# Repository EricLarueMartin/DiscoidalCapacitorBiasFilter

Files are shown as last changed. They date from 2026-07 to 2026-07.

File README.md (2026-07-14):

# Discoidal Capacitor Bias Filter

This repository contains the design, simulation, prototyping, and presentation tools for a high-voltage, low-current detector bias filter built from a discoidal capacitor stack. The project is named for the geometry being analyzed; a later implementation is expected to serve SHV connector inputs, but connector packaging is outside the present analysis. The project was developed around an AI-managed Raspberry Pi: the AI works from your computer, connects to the Pi over SSH, installs the solver stack, hosts the web interface, and tests the deployment.

## What You Need

The recommended setup is:

- A Raspberry Pi 5 with 4 GB RAM is the recommended target. The measured default FEniCSx solves also fit comfortably on a 2 GB Pi when the backend runs its normal single worker. A Pi 4 with 2 GB or more should be usable, but finite-element solves will be slower. An 8 GB model is useful for unusually fine meshes or additional development services, but is not required for the present application.
- A 64 GB high-endurance microSD card. A 32 GB card is a practical minimum.
- The correct Raspberry Pi power supply.
- Ethernet or Wi-Fi access to the same network as your computer, with Internet access during installation.
- A Windows, macOS, or Linux computer from which an AI coding agent can edit this repository and connect to the Pi by SSH.
- A microSD card reader for installing Raspberry Pi OS.

A monitor and keyboard for the Pi are optional. Raspberry Pi Imager can preconfigure the network and SSH, and Raspberry Pi Connect is a useful fallback during initial setup.

If you already have a suitable Pi running on your network, use it; the agent runbook begins by discovering what is already complete and skips unnecessary setup.

### Measured Memory Use

Resource monitoring around the actual FEniCSx subprocesses was added before setting the hardware recommendation. With the default two-pair geometry and default meshes on a Raspberry Pi 5, the electric-field solve peaked at 156.5 MiB of solver-process RSS and the thermal-stress solve peaked at 251.8 MiB. Peak total system memory in use was approximately 655 MiB and 771 MiB respectively, and neither solve used swap.

These measurements support 2 GB as a practical minimum and 4 GB as the recommended capacity for ordinary development. They are not hard upper bounds: the FEniCSx direct linear solver can grow substantially faster than the mesh dimensions, so aggressive mesh refinement, larger full-stack models, parallel solves, or unrelated services may need more RAM. The backend intentionally runs one FEA worker at a time. Each solve records its geometry, reduction strategy, peak process memory, lowest available system memory, and swap use in the ignored runtime log `simulations/axisymmetric/logs/fea-resource-usage.jsonl` so this guidance can be updated as larger cases are exercised.

Setting up a Pi is worthwhile beyond this one project. Once provisioned, it becomes a reusable development and test environment for other web services, simulations, instruments, and automation projects. It can communicate over Wi-Fi, run without a monitor or keyboard, and be placed wherever it is convenient for the work at hand while your AI agent continues to control it remotely over SSH.

The recommended trust model is to treat the Pi as an AI development appliance rather than a durable server. Give the dedicated AI account full administrative control, including `NOPASSWD` sudo, so the agent can install packages, change services, reboot, and repair the environment without repeatedly stopping for authorization. Keep source and important results in Git or another external location. If the agent damages the operating system beyond convenient repair, reimaging the microSD card provides a clean recovery path.

This model assumes a dedicated, expendable development Pi with no irreplaceable local data. Do not apply blanket AI access to a shared, production, or security-sensitive server.

## Start With An AI

You are probably reading this README on the project's GitHub page, where GitHub displays it below the repository file list. You do not need to follow a long list of shell commands here. Choose one of the guides below; it will show you how to use the **Code** menu on this page to put the repository on your computer, open it with the AI, and ask the AI to walk you through the setup at whatever level of detail you need.

- [Codex desktop app](docs/getting-started/chatgpt-codex-app.md) - the workflow used to develop this project.
- [Visual Studio Code with the Codex extension](docs/getting-started/vscode-codex.md) - for working beside the files in an editor.
- [Codex command line](docs/getting-started/codex-cli.md) - for a terminal-first OpenAI workflow.
- [Claude Code](docs/getting-started/claude-code.md) - for a terminal-first Anthropic workflow.
- [Another local coding agent](docs/getting-started/other-agent.md) - requirements and a provider-neutral starting prompt.

The agent-facing Raspberry Pi runbook is [deploy/pi/agent-setup.md](deploy/pi/agent-setup.md). Humans can read it, but it is written for an agent that can inspect the local machine, generate an SSH key, substitute the real public key into commands, connect to the Pi, install packages, and verify the result. You should never have to replace `PASTE_PUBLIC_KEY_HERE` or similar placeholder text yourself.

## Optional Local-Computer Setup

If you only want to run this web service, a Raspberry Pi is not required. The browser interface and the project's own Python HTTP backend can run directly on your local computer. No separate web framework is required.

Local hosting is a supported option, but it is not the environment in which the project was developed. The complete FEniCSx path is most straightforward on Raspberry Pi OS or another Debian-based Linux system; on Windows, an agent may recommend WSL 2 for the solver backend.

Tell your chosen agent that you want a local-only installation and have it adapt [deploy/pi/package-requirements.md](deploy/pi/package-requirements.md) to your operating system. It should explain which features it verified and which remain Pi-specific.

## Concept

The filter is based on a cylindrical, discoidal capacitor stack:

- Alternating high-voltage center plates and grounded annular plates.
- A central resistive core in the 100 Mohm to low Gohm range.
- Dielectric between overlapping HV and ground plate regions to provide useful capacitance.
- Lower-permittivity dielectric near the resistive core and outer fringe regions to reduce parasitic capacitance where appropriate.
- Flat ceramic washer slabs in the axial gaps between plate faces, with epoxy fill in rounded-edge pockets and other non-washer voids.
- Separate outer ground rings that can couple to a surrounding tube, allowing adjustment of ground separation between input and output.
- Prototype I/O based on screw terminals, with later revisions expected to directly support SHV bulkhead connectors.

## Repository Map

- `docs/getting-started/` - short human guides for opening the project with an AI agent.
- `deploy/pi/` - agent-facing Raspberry Pi installation and hosting runbooks.
- `docs/knowledge/` - curated design knowledge, requirements, assumptions, and decisions.
- `docs/chats/raw/` - raw AI collaboration transcripts and exported chats.
- `docs/chats/markdown/` - cleaned summaries derived from raw chats.
- `hardware/` - geometry, materials, connector, and prototype design notes.
- `simulations/` - simulation plans, parameter definitions, and solver work.
- `presentations/web/` - the interactive web designer and presentation.
- `software/` - calculation, geometry, solver, and backend code.

## Current Tooling

The repository includes an axisymmetric geometry and electrostatic model:

```powershell
python software/bias_filter/axisymmetric_model.py export
python software/bias_filter/axisymmetric_model.py solve
python software/bias_filter/axisymmetric_model.py cad
```

The browser page at `presentations/web/index.html` mirrors the same first-order r-z model for interactive design changes and peak-field screening. CAD and mesh exports are generated under `hardware/geometry/generated/`.

The JavaScript and Python finite-difference solvers are structured-grid screening tools. The optional FEniCSx/DOLFINx backend uses a conforming Gmsh r-z dielectric domain and reports field and capacitance checks, including an adjacent-bias parasitic-capacitance estimate from a separate three-bias-plate solve. Peak-field results still require mesh-convergence work before they should be treated as validated breakdown limits.

The backend also provides RC-ladder and SPICE-style response calculations using `ngspice` when available, with an internal modified-nodal fallback.

## AI Collaboration

Agents should read the root `AGENT.md`, the nearest directory-specific `AGENT.md`, and [deploy/pi/agent-setup.md](deploy/pi/agent-setup.md) before installing or deploying the project. Hostnames, IP addresses, passwords, private keys, and current deployment paths belong in ignored local files, never in committed documentation.

The current cross-computer continuation note is
[docs/chats/markdown/2026-07-13-current-handoff.md](docs/chats/markdown/2026-07-13-current-handoff.md).

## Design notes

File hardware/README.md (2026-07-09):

# Hardware

Hardware notes are split into:

- `geometry/` - Plate, tube, core, and dielectric geometry.
- `materials/` - Ferrite, dielectrics, metals, resistors, and connector materials.
- `prototypes/` - Build plans and test notes for prototype revisions.
- `degas-controller/` - Vacuum/pressure cycling controller for epoxy void reduction.

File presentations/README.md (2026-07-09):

# Presentations

This section hosts web-based presentations and design views that can be viewed in a browser, version-controlled, and eventually published with GitHub Pages or another static site host.

Start with `web/index.html`. The first screen is an interactive geometry and electric-field design view, with slide material available as a tab.

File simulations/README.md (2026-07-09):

# Simulations

The first simulations should be electrostatic and axisymmetric.

Primary questions:

- What peak electric fields appear at rounded plate edges?
- How sensitive are fields to edge radius and plate gap?
- How much capacitance is produced per discoidal gap?
- How should dielectric boundaries be placed near the end of plate overlap?
- What changes when the outer ground tube is present?

## Current Script Path

The first repository-native model is `software/bias_filter/axisymmetric_model.py`.

It can export geometry and run a compact r-z finite-difference electrostatic solve:

```powershell
python software/bias_filter/axisymmetric_model.py export
python software/bias_filter/axisymmetric_model.py solve
python software/bias_filter/axisymmetric_model.py cad
```

Generated summaries and SVGs are written to `simulations/axisymmetric/outputs/`.
CAD and mesh exports are written to `hardware/geometry/generated/`.

This model treats the central ferrite/resistive core as a conductive HV body for electrostatic field screening. The free dielectric from the core surface to the ground-plate inner radius is epoxy/fill. Washer material is present only as flat annular slabs in the axial gaps between adjacent plate faces. Rounded-edge pockets, tube-side fill, and other non-washer voids are epoxy. Flow holes in the HV plates are omitted from the axisymmetric model and should be checked later with a local 3D study if their dimensions approach high-field regions.

The peak-field search is a global scan over all dielectric grid nodes after solving the potential, not a single-start local optimizer. To reduce the chance that a narrow peak is missed before adaptive refinement, the grid is seeded in three deterministic ways before the probe solve: rounded conductor-edge neighborhoods, dielectric-side points radially away from the HV outer and ground inner plate edges, and washer-region points centered between adjacent plate faces. The later high-field adaptive pass then adds extra coordinates around all dielectric nodes above the configured field threshold.

The current peak is a screening metric. The UI reports `Supported Emax`, based on a same-material local neighborhood, and keeps the raw point maximum as a diagnostic. It includes a near-conductor sliver guard to avoid obvious nonconformal-grid spikes, but mesh sweeps still show that the maximum near rounded conductors can move between edge features. Treat supported and raw peaks as warning indicators and use them for relative comparisons only.

The default washer-overlap field remains the first sanity check for every solver path: with 6 kV across 1 mm, samples away from edges should be about 6.0 kV/mm. This check is now documented because it caught an early FEniCSx boundary-tagging failure. After the 2026-06-25 tolerance fix, both FD and deployed FEniCSx return about 6000 V/mm in the default flat washer gaps.

Field-map colors in the web app use one absolute `V/mm` scale. Dielectric breakdown values may appear as reference ticks and margin readouts, but they should not normalize individual pixels when the colorbar is labeled in kV/mm.

## RF Model Roadmap

The current frequency-response plot is a lumped RC ladder with a parasitic capacitance branch. It is useful for intuition and parameter sweeps, but it is not a field-based RF calculation.

The next field-based comparison should probably be a frequency-domain quasi-static admittance solve before a full-wave model. That solve would use the same axisymmetric geometry and complex material coefficient:

```text
div((sigma + j omega epsilon) grad(V)) = 0
```

This captures dielectric permittivity, dielectric loss if added, finite conductor conductivity, and frequency-dependent current paths while staying close to the existing electrostatic formulation. The web parameters now include plate and tube material names, conductivity `sigma`, relative permeability `mu_r`, and a comparison frequency; defaults use copper for both plates and tube.

A full-wave RF model is a separate tier. FEniCSx-style FEM can represent Maxwell problems with suitable vector/edge elements, but a useful implementation also needs port definitions, radiation or absorbing boundaries/PML where appropriate, conductor loss treatment, and validation against the simpler admittance and lumped RC models. For this filter size and the likely noise frequencies of interest, use the quasi-static admittance backend as the first repository-native RF target.

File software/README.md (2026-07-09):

# Software

This directory is reserved for future project software, including:

- Geometry parameter tools.
- Capacitance and resistance calculators.
- Simulation pre/post-processing.
- Presentation generation tools.
- Data analysis from prototype measurements.

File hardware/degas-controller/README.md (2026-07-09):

# Degas Controller

Subproject for controlling the vacuum/pressure cycling used to reduce voids during epoxy potting.

## Prototype Function

- Control two valves through relays:
  - vacuum valve: opens the chamber to a vacuum pump.
  - pressure valve: opens the chamber to a pressure source, initially vent or nitrogen.
- Read chamber pressure from a pressure gauge or pressure transducer.
- Cycle between low-pressure and high-pressure dwell bands before heat cure.

## User Controls

- Low-pressure target.
- High-pressure target.
- Hysteresis band around each target for valve open/close control.
- Dwell time at each pressure band.
- Number of vacuum/pressure cycles.

## Notes

Pressure curing inside an oven could be useful later, but it is intentionally outside the first prototype scope. The first controller should focus on repeatable degas cycling at room temperature with clear valve-state logging and conservative pressure-vessel safety margins.

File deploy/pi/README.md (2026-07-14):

# Raspberry Pi Web Host

This directory contains reusable Raspberry Pi hosting support for the Discoidal Capacitor Bias Filter web app and solver backend. Keep site-specific hostnames, IP addresses, local checkout paths, passwords, and private keys in ignored local notes such as `.secrets/current-deployment.md`.

The recommended deployment is a dedicated AI development Pi with blanket passwordless sudo for the `agent` account. The agent may administer the machine as needed, while Git or other off-device storage holds the durable copy of the work. Reimage the microSD card if experimentation leaves the OS in an inconvenient state. Use narrower privileges when adapting these files to a shared or production host.

The root README sends humans to a short guide for their chosen coding agent. That agent should then follow [agent-setup.md](agent-setup.md) from the user's current starting point, including OS guidance and creation of dedicated SSH access. Package details are split into [package-requirements.md](package-requirements.md).

## Layout

The agent setup guide uses these variables:

- `PROJECT_DIR` - repository checkout or synced working tree on the Pi.
- `STATIC_ROOT` - web server document root on the Pi.
- `APP_PATH` - URL path for the app, usually `/discoidal-capacitor-bias-filter/`.
- `STATIC_DIR` - static files for the app, usually `STATIC_ROOT` plus `APP_PATH`.
- `SERVICE_NAME` - systemd service name.

The included service file contains placeholders. The setup agent must render it with the user's chosen `AGENT_USER`, `PROJECT_DIR`, and `STATIC_ROOT` before installing it.

## Service

`agent-sites.service` runs the repository's dependency-free Python field backend on port 80 as the agent user. It serves the landing page, the Discoidal Capacitor Bias Filter web app, and `/api/field-solve` job endpoints. The service uses `AmbientCapabilities=CAP_NET_BIND_SERVICE` so it can bind port 80 without running as root.

The backend accepts `--solver fd`, `--solver auto`, and `--solver fenicsx`. The Pi package stack for FEniCSx/DOLFINx/Gmsh is installed and the conforming worker is implemented. The service is still intentionally started with requested/effective default solver `fd` so normal page loads use the faster screening path; use the web dropdown's `FEniCSx required` option when deliberately running the conforming FEA worker.

The systemd unit sets `MemorySwapMax=0`. The backend and all FEniCSx subprocesses therefore stay in the same no-swap cgroup, avoiding solver-driven swap writes on SD-card deployments. If a solve exhausts available RAM, it should fail rather than spill into swap; keep the worker count at one and reduce mesh density for oversized jobs.

## Reporting Access

After setup, the agent must report the actual hostname or IP address it verified, using clickable links for the app and backend health endpoint. Do not commit those current-access details to this repository.

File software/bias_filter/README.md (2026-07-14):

# Bias Filter Tools

`axisymmetric_model.py` provides a lightweight parameterized model for early design iteration.

Examples:

```powershell
python software/bias_filter/axisymmetric_model.py export
python software/bias_filter/axisymmetric_model.py solve
python software/bias_filter/axisymmetric_model.py cad
```

The solver is a first-order finite-difference electrostatic model in an r-z cross-section. It is intended for trend finding, geometry review, and peak-field screening before higher-fidelity validation.

CAD exports are written to `hardware/geometry/generated/` as OpenSCAD, OBJ/MTL, and STL files. The CAD/mesh profiles use the same parameter interpretation as the axisymmetric solver.

## Pi Field Backend

`field_backend.py` stages the HTTP backend that the web designer already tries before falling back to browser JavaScript. It uses only Python's standard library so it can run on a Raspberry Pi without installing a web framework:

```powershell
python software/bias_filter/field_backend.py --host 0.0.0.0 --port 8765
```

Open `http://<pi-hostname-or-ip>:8765/` from the browser. The server exposes:

- `POST /api/field-solve`: accepts `{ "client_id": "...", "solver": "fd|auto|fenicsx", "parameters": { ... } }` and returns a queued `job_id`.
- `GET /api/field-solve/{job_id}`: returns queued, running, failed, or complete job state.
- `POST /api/geometry`: accepts `{ "parameters": { ... } }` and returns the sanitized solver-side r-z component profiles without running a field solve.
- `POST /api/spice-ladder`: accepts `{ "parameters": { ... } }` and returns a SPICE-style small-signal AC ladder sweep, generated netlist text, and summaries for the RC ladder plus coax transmission-line load.
- `POST /api/thermal-solve`: runs the axisymmetric linear-thermoelastic FEniCSx solid model synchronously and returns epoxy tensile-stress percentiles, the raw corner peak, mesh statistics, and model assumptions.
- `GET /api/health`: lightweight server status.

Jobs are independent and write under `simulations/axisymmetric/jobs/{job_id}/`, avoiding shared `latest-*` output files for browser requests. The default worker uses the repository finite-difference axisymmetric solver; explicit FEniCSx jobs run in a subprocess so Gmsh and PETSc are isolated from the web worker thread.

Every electric-field or thermal FEniCSx subprocess is sampled from Linux `/proc` at 0.1 s intervals. The solve tabs show peak solver-process RSS, peak system memory use, lowest available system memory, and maximum system swap use. The backend appends the complete sanitized inputs, solve status, mesh summary, full-stack/mirror/repeating-cell choices, process-tree RSS and swap, and system-memory extrema to `simulations/axisymmetric/logs/fea-resource-usage.jsonl`. This runtime log is intentionally ignored by Git; retain or analyze it on each Pi when developing hardware recommendations.

The first monitored default solves on a Raspberry Pi 5 used 156.5 MiB peak process RSS for the electric FEA and 251.8 MiB for the thermal FEA. Corresponding peak total system use was approximately 655 MiB and 771 MiB, with no swap use. The project therefore recommends 4 GB RAM for comfortable development and treats 2 GB as the practical minimum for the present single-worker service. Fine meshes and larger direct solves can require substantially more memory; continue using the accumulated runtime log rather than treating these first measurements as fixed upper bounds.

The backend has a staged solver selector:

```powershell
python software/bias_filter/field_backend.py --solver fd
python software/bias_filter/field_backend.py --solver auto
python software/bias_filter/field_backend.py --solver fenicsx
```

`fd` is the nonuniform finite-difference screening solver. `auto` may select FEniCSx when the optional package stack is installed and the solver reports ready. `fenicsx` deliberately requires that optional path and fails loudly when it is not ready.

The field backend is still electrostatic. Plate and tube conductivity/permeability parameters are passed through job inputs and summaries so a later frequency-domain admittance or RF backend can consume the same design payload, but the present `fd` solver treats conductors as equipotential boundaries.

The `/api/spice-ladder` endpoint is separate from the electrostatic field solve. On the deployed Pi it uses `ngspice` batch AC analysis when available, with an internal Python modified-nodal AC solve as a fallback for development machines without ngspice. The returned netlist uses ordinary SPICE concepts (`R`, `C`, and a lossless transmission-line `T` element), so the simulation can be inspected or rerun directly in ngspice.

The `/api/thermal-solve` endpoint is also separate from the electrostatic field solve. It meshes the full bonded copper/alumina/epoxy/core r-z solid and uses exact cylindrical and center-plane symmetry. The closed-form differential-contraction estimate remains in the web app as an independent baseline. The FEA assumes perfect bonds, traction-free exposed surfaces, linear elasticity, and a 70 C stress-free reference; it does not model cure shrinkage, relaxation, voids, or debonding.

The backend SPICE sweep and matching web attenuation plots are fixed at 1 Hz to 100 MHz. This makes the low-frequency rolloff around power-line noise easier to read while avoiding excessive very-slow-drift plot space, and 100 MHz is a practical upper view limit for the current detector readout context because the DAQ sample rate is only about 200 MS/s.

The web Designer exposes the same distinction as a dropdown: `Backend adaptive FD` means Python-backed finite difference, not FEniCSx. `FEniCSx required` is the explicit conforming FEA path.

The current `fd` worker solves the cylindrical axisymmetric r-z equation with radial face weighting, not the rectangular-coordinate Laplacian. It is still a nonconformal structured-grid solver. The point maximum near rounded conductor boundaries is labeled as a screening value because it remains mesh-sensitive; the overlap fields away from edges should be checked against `V / gap` and are the better regression sanity check until conforming FEA is available.

Both the FD and FEniCSx workers report a neighborhood-supported peak field plus the raw point maximum. Use the supported value for interactive screening and the raw point as a mesh-artifact diagnostic.

The current FEniCSx worker builds a conforming Gmsh/OpenCASCADE r-z dielectric domain with conductor regions removed as holes, solves the cylindrical weak form in DOLFINx, and samples `|grad(V)|` back onto the browser grid for comparison. It reports total two-terminal capacitance from the axisymmetric dielectric energy integral, `C = 2U/V^2`, and a quasi-static shunt admittance sweep using `Y(f) = Iload/Vbias + j 2 pi f C`. The load-current slider defaults to 1 nA.

The FEniCSx worker also reports an adjacent-bias `Cpar` estimate from a separate local three-bias-plate model. Three energy solves drive the middle plate, both neighbors, and all bias plates respectively; polarization then cancels ground-capacitance terms algebraically. This is an energy-based design sanity check, not yet a full capacitance-matrix charge extraction.

For MELF 0204/0207 presets, the Cpar solves include the inter-plate core as dielectric with an effective permittivity `eps_eff = eps_substrate / (1 - film_fill_factor)`. The default 0207 values are `eps_substrate = 9.8` and `film_fill_factor = 0.50`. In the capacitance-only geometry, each bias plate extends across the core cross-section as a stage-node electrode, but the core between plates remains dielectric. Adjacent-stage mutual capacitance uses three energy solves (middle only, neighbors only, and all bias plates) so polarization cancels capacitance to ground without assuming equal edge and middle ground capacitances. This remains an initial FEA backend, not yet a production acceptance calculation, because the peak-field convergence loop, mesh-refinement records, capacitance-matrix charge extraction, and lossy complex-permittivity FEM admittance solve still need to be added.

The analytic core-plus-epoxy Cpar estimate is intentionally a parallel-plate upper-level sanity check. It does not model field intercepted by the intervening ground-plate inner edge. When the ground-hole radius is comparable to or smaller than the adjacent-bias separation, FEA can therefore report materially less epoxy-mediated adjacent-stage coupling even after the core dielectric treatment is correct.

The Pi solver includes a repeatable Type 61 limiting-geometry comparison. It expands the core-ground radial gap while preserving radial plate overlap and reports FEA/analytic Cpar; that ratio should approach unity as the hole radius becomes large compared with stage spacing:

```bash
python3 software/bias_filter/fenicsx_solver.py --validate-cpar-gap-sweep
```

FEniCSx conductor boundary tagging uses a small geometric tolerance. This is required because Gmsh/DOLFINx boundary coordinates can land infinitesimally outside ideal plate intervals; exact classification previously missed one side of some conductor faces and produced washer-gap fields far below `V / gap`.

The field material model is z-dependent. Flat washer material exists only in the axial gaps between adjacent plate faces and between the explicit washer ID/OD. The defaults tie washer ID to ground plate ID and washer OD to HV plate OD; smaller custom washers leave the newly exposed radial pockets as epoxy.

Keep the flat-gap sanity check in any solver review: for default 6 kV bias and 1 mm washer thickness, samples in the radial and axial middle of each washer overlap should be about 6000 V/mm. The deployed Pi FEniCSx API passed this check on 2026-06-25.

Check optional FEniCSx dependency readiness with:

```powershell
python software/bias_filter/fenicsx_solver.py --json
```

Run backend tests with:

```powershell
python -m unittest software.bias_filter.test_field_backend
```

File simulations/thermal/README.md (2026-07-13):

# Thermal mismatch screen

`software/bias_filter/thermal_stress.py` evaluates the default cured copper,
alumina, and MG Chemicals 9510 assembly with a closed-form restrained-epoxy
model. Run it with:

```powershell
python software/bias_filter/thermal_stress.py
```

The checked-in result is `outputs/default-thermal-stress.json`. It preserves
the source material properties, assumed epoxy modulus range, equations,
geometry dimensions, a room-temperature evaluation point, failure-onset
sensitivity limits, and interim transport guidance. The evaluation temperature
is a what-if calculation point, not a design target.

This is deliberately a conservative design screen. It is not an adhesive
fracture or thermal-cycle qualification because the 9510 datasheet does not
publish elastic modulus, copper/alumina pull-off strength, or interface
fracture toughness. The result therefore reports a full-restraint upper bound
and a 50% restraint sensitivity rather than hiding the uncertainty in a single
claimed rating.

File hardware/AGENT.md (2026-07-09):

# Agent Guide: hardware

Use this directory for physical design, materials, connector choices, prototype notes, and assembly constraints.

Keep hardware notes parameterized where practical. Avoid burying design decisions only in CAD files or images.

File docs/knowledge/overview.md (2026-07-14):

# Knowledge Overview

## Goal

Build a compact high-voltage bias filter around a discoidal capacitor stack for detector systems that need high bias voltage and very low current. The electrical and geometric analysis is connector-independent. A later implementation is expected to serve LEGEND-style SHV inputs and sub-nA detector currents.

## Baseline Architecture

The proposed filter is cylindrical and approximately axisymmetric. It combines:

- A center high-voltage path.
- A large series resistance.
- Alternating discoidal capacitive plates.
- Ground-connected annular plates.
- Dielectric regions chosen to shape capacitance and electric field.
- An optional outer grounded tube coupled to the ground rings.

## Development Priorities

1. Define geometry and safe electric-field margins.
2. Simulate rounded plate edges and dielectric transitions.
3. Prototype with simple screw-terminal input/output.
4. Evaluate NiZn ferrite as a resistive core.
5. Compare against a MELF resistor chain if ferrite noise, stability, or manufacturability is poor.
6. Evolve the mechanical interface toward direct SHV bulkhead connectors.

## Current Status

The web designer and Raspberry Pi backend are active enough for collaborative screening. The default deployed solver is an axisymmetric cylindrical finite-difference model with local structured-grid refinement. It gives sensible washer-overlap fields, including the default 6 kV across 1 mm result of about 6.0 kV/mm away from edges.

The optional FEniCSx backend now runs a conforming axisymmetric electrostatic solve on the Pi when `FEniCSx required` is selected. Both solver paths use the current physical dielectric interpretation: flat washer slabs only in axial gaps between plate faces, with epoxy filling rounded-edge pockets and other non-washer voids.

The current FEniCSx deployment has passed the simplest field-scale regression: default 6 kV bias across each 1 mm flat washer gap samples at about 6.0 kV/mm in the radial middle of the plate overlap. This check caught and fixed an early boundary-tagging bug, so keep it as the first sanity check after solver changes.

The FEniCSx backend now reports two capacitance sanity checks. Total HV-to-ground capacitance comes from the ordinary all-HV energy integral. Adjacent-bias parasitic capacitance is estimated with a separate local three-bias-plate solve and energy subtraction: middle bias plate driven, neighboring bias plates grounded, representative ground capacitance subtracted, then divided by two. MELF presets model the resistor body as a ceramic core with an effective metal-film fill factor rather than a fixed package Cpar.

The remaining unresolved simulation issue is peak-field convergence at rounded conductor edges. The web UI reports a neighborhood-supported Emax and keeps the raw point maximum as a diagnostic, but neither the finite-difference peak nor the initial FEniCSx peak should be used for dielectric-breakdown acceptance until a mesh-convergence loop is in place.

The field-map color scale is absolute electric field in V/mm. Dielectric breakdown values are displayed as reference/margin information only, so color intensity should now correspond directly to the colorbar scale.

Current Pi hostnames, IP addresses, checkout paths, and access URLs are deployment-local information. Keep them in ignored `.secrets/` notes and have the setup agent report the verified clickable URL after installation.

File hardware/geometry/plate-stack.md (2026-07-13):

# Plate Stack Geometry

## Named Parameters

| Parameter | Meaning |
| --- | --- |
| `core_od` | Outside diameter of the central resistive core or HV path |
| `tube_id` | Inside diameter of the optional outer ground tube |
| `ground_plate_od` | Outside diameter of each ground-connected annular plate |
| `hv_plate_od` | Outside diameter of each high-voltage center plate |
| `washer_id` | Inner diameter of the ceramic washer slab; by default follows the ground plate ID |
| `washer_od` | Outer diameter of the ceramic washer slab; by default follows the HV plate OD |
| `plate_gap` | Axial gap between neighboring plates |
| `plate_thickness` | Axial thickness of each conductive plate |
| `edge_diameter_percent` | Web-control value for rounded-edge diameter as a percentage of `plate_thickness`; `100` gives radius `plate_thickness / 2` |
| `edge_radius` | Derived rounded-edge radius used by simulation/export code |
| `washer_epsr` | Relative permittivity of the flat washer slabs between adjacent plate faces |
| `epoxy_epsr` | Relative permittivity of epoxy fill in core-side gaps, tube-side gaps, regions outside the washer annulus, and other voids |

## Modeling Notes

The axisymmetric r-z model should represent rounded edges explicitly rather than approximating them as sharp corners. The first geometry cases should isolate local field behavior before modeling a full multi-section filter.

## Dielectric Regions

The working model separates these material zones:

- Ferrite or other resistive core material on the central high-voltage path. The electrostatic field solve treats this core as an HV equipotential body.
- Flat washer dielectric slabs in the axial gaps between adjacent plate faces, spanning from the entered washer ID to washer OD. The washer dimensions are primary. Relation modes can derive the ground inner diameter and bias outer diameter either at the conductor extrema or at the start of their rounded edge sections; Custom mode leaves the plate diameters independent.
- Epoxy fill in the core-side gaps, tube-side gaps, regions outside the washer annulus, and remaining volume.

For capacitance estimates, use the explicit washer ID/OD overlap. If a custom washer is smaller than the plate overlap, the exposed rounded-edge pockets are epoxy in the field material map.

HV plates may eventually include flow holes for vacuum degassing and epoxy fill. These are intentionally omitted from the initial axisymmetric electrostatic model because small azimuthal holes should have limited effect on the bulk axisymmetric field. A later 3D local study can check hole-edge field enhancement if the holes are large, numerous, or close to high-field regions.

The canonical starting parameter set lives in `default-parameters.json`.

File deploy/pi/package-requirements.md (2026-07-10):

# Pi Package Requirements

This file is for the setup agent. Install these packages on Raspberry Pi OS 64-bit or Debian arm64 before starting `agent-sites.service`.

Before installing packages, verify `uname -m` reports `aarch64` and inspect `/etc/os-release`. These commands assume an APT-based 64-bit Raspberry Pi OS or Debian-family system. Do not silently omit the FEniCSx packages if the distribution cannot provide them; explain the mismatch and recommend a supported 64-bit Raspberry Pi OS image.

## Required Base Packages

```bash
sudo apt update
sudo apt install -y \
  git \
  openssh-server \
  curl \
  rsync \
  python3 \
  python3-venv \
  python3-pip
```

## FEniCSx / Gmsh Backend Packages

Install these so the web app can run the conforming FEniCSx field backend:

```bash
sudo apt install -y \
  fenicsx \
  gmsh \
  python3-gmsh \
  python3-dolfinx \
  python3-ufl \
  python3-mpi4py \
  python3-petsc4py
```

## SPICE Backend Package

Install `ngspice` when available. The backend has an internal Python fallback, but `ngspice` is preferred for the SPICE-style ladder endpoint.

```bash
sudo apt install -y ngspice
```

## Import Checks

Run these after installation:

```bash
python3 - <<'PY'
import dolfinx, gmsh, mpi4py, petsc4py, ufl
print("FEniCSx import check passed")
PY
```

```bash
ngspice -v
```

If `ngspice` is unavailable, continue with setup and note that `/api/spice-ladder` will use the internal modified-nodal fallback.

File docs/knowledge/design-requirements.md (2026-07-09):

# Design Requirements

## Electrical

- Initial voltage envelope: up to about 6 kV for SHV-based versions.
- Detector current: typically sub-nA for LEGEND and similar detector bias applications.
- Series resistance target: approximately 100 Mohm to low Gohm.
- Filtering should reduce bias noise while avoiding excess parasitic capacitance around the resistive core.
- Track the RC ladder values: per plate-pair capacitance, per-node capacitance to ground, resistance between adjacent bias plates, and bias-to-bias parasitic capacitance.
- At high frequency, track the approximate capacitive feedthrough ratio `C_parasitic / C_ground`; see `rc-network.md`.
- Do not size bias-path resistors as if they must hold the full 6 kV DC supply in normal operation. Their steady drop is set by detector load current times resistance; see `resistor-voltage-stress.md`.
- Track capacitance improvement relative to FR4/G10 washers so the prototype can estimate the value of later ceramic washer upgrades.
- Prefer non-piezoelectric washer dielectrics; piezoelectric or ferroelectric high-K ceramics are likely unsuitable because detector-bias microphonics could matter.
- In the web interface, clearance-like geometry controls should use the selected washer material's provisional dielectric strength to set the minimum spacing and a 10x design-factor maximum. Custom or generic screening materials should use a fixed `0.4 mm` to `4 mm` range until backed by a specific material.

## Mechanical

- Cylindrical symmetry should be preserved where practical.
- Early prototypes may use screw terminals for input and output.
- Alumina washers are the preferred prototype dielectric if suitable parts can be sourced.
- Early prototypes may use FR4/G10 washers if ceramic washers are unavailable or too difficult to machine.
- Later prototypes should support direct connection to SHV bulkhead connectors.
- Ground rings should remain separable enough that an outer tube can adjust ground separation between input and output.

## Field Control

- Plate edges should be rounded.
- Initial edge-radius assumption: radius equals half the plate thickness.
- Simulations should focus on inner and outer rounded-edge regions.
- Dielectric boundaries should be included because field fringing may affect optimal material placement.

## Adaptability

The design should not be hard-coded to LEGEND. Parameters should allow alternate detector experiments, connector types, voltage limits, current ranges, dielectrics, and resistance strategies.

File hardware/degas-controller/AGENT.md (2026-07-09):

# Agent Guide: hardware/degas-controller

Use this directory for the vacuum/pressure degas controller subproject.

Keep notes explicit about pressure ranges, valve states, relay wiring, pressure-sensor calibration, safety interlocks, and test fixtures. Treat pressure-vessel and mains-powered relay work as safety-critical until reviewed by the user.

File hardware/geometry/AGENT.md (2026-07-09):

# Agent Guide: hardware/geometry

Use this directory for geometry definitions and mechanical design notes.

Track dimensions as named parameters where possible, and keep the relationship to simulation parameters clear.

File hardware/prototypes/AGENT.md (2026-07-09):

# Agent Guide: hardware/prototypes

Use this directory for prototype build plans, assembly notes, test results, and revision history.

Each prototype should record purpose, materials, dimensions, expected resistance, expected capacitance, voltage target, test setup, and observed issues.

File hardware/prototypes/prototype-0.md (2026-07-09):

# Prototype 0

## Purpose

First physical exploration of the discoidal bias-filter concept.

## Planned Simplifications

- Screw-terminal input and output.
- Parameterized plate stack rather than final connector integration.
- Candidate NiZn ferrite central resistive core.
- Rounded plate edges with radius initially equal to half the plate thickness.

## Candidate Materials

- Washer dielectric: alumina is the preferred first target; FR4/G10 remains the easiest fallback if suitable alumina washers are unavailable; piezoelectric high-permittivity electroceramics are screening-only and likely no-go because of microphonics.
- Potting and fill: MG Chemicals 9510 One-Part Epoxy Potting Compound, Heat Cure.
- Resistive core / conductor path: Fair-Rite type 61 NiZn ferrite is the first concrete sample set, tested with 4 mm, 5 mm, and 6 mm diameter samples. Keep the web model generic enough to compare other core material placeholders.
- Ferrite-to-plate contact: conductive epoxy, exact product TBD.
- Mechanical positioning: spacers with epoxy flow paths to hold the plate, washer, and ferrite-disc stack during cure and potting.

## Candidate Assembly Flow

- Cut ferrite samples into discs with a diamond saw.
- Polish discs to target thickness and inspect the edges and faces.
- Polish copper bias and ground discs before assembly.
- Bond ferrite or other core-material discs to bias plates with conductive epoxy.
- Use spacers with flow holes to maintain the intended plate spacing and alignment while allowing epoxy to fill around the stack.
- Add alumina washer dielectric sections in the HV-to-ground overlap regions if suitable washers can be sourced. Use FR4/G10 only as the fallback geometry/process prototype.
- Pot the assembly with MG Chemicals 9510.
- Vacuum degas with repeated vacuum and pressure cycles before heat cure. The pressure source may initially be vent or nitrogen.

## Degas Controller Need

Prototype potting will need a separate degas-controller subproject. The controller should drive two relay-switched valves: one from the chamber to the vacuum pump and one from the chamber to the pressure source. It should monitor chamber pressure and support user-set low pressure, high pressure, hysteresis band around each pressure target, dwell time at each band, and repeat count.

Pressure-cure integration in an oven could be useful later, but the first controller should focus on room-temperature vacuum/pressure cycling before heat cure.

## Measurements To Capture

- DC resistance.
- Leakage current versus voltage.
- Noise under representative detector-bias conditions.
- Breakdown or partial-discharge behavior if test equipment allows.
- Capacitance from HV path to ground.
- Parasitic capacitance between adjacent bias plates.
- Conductive-epoxy contact resistance.
- Resistance and leakage before and after potting and heat cure.
- Microscopy or visual inspection of cut and polished ferrite surfaces.
- Evidence of trapped voids, cracks, epoxy shrinkage, or partial-discharge damage.
- Capacitance improvement relative to FR4/G10 for alumina and any later non-piezo ceramic washer candidate.
- Dielectric loss, leakage, voltage coefficient, and microphonic response of any non-alumina high-permittivity washer candidate.

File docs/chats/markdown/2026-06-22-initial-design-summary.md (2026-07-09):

# Initial Design Summary

Sources:

- `../raw/2026-06-22-initial-repo-seed.txt`
- `../raw/2026-06-23-web-materials-edge-rc-continuation.txt`
- `../raw/2026-06-23-pi-fea-backend-client-handling.txt`
- `../raw/2026-06-23-gap-parameterized-geometry-controls.txt`
- `../raw/2026-06-23-breakdown-based-spacing-ranges.txt`
- `../raw/2026-06-23-epoxy-material-and-epsilon-ui.txt`
- `../raw/2026-06-23-live-generated-slide-graphics.txt`
- `../raw/2026-06-23-radial-gap-label-clarification.txt`
- `../raw/2026-06-23-js-field-solver-commentary.txt`
- `../raw/2026-06-23-core-resistivity-derived-resistance.txt`
- `../raw/2026-06-23-pi-backend-scaffold.txt`
- `../raw/2026-06-23-dielectric-breakdown-margins.txt`
- `../raw/2026-06-23-conductive-core-field-region-correction.txt`
- `../raw/2026-06-23-default-plate-pairs-edge-diameter.txt`
- `../raw/2026-06-24-single-stage-rc-ladder-drawing.txt`
- `../raw/2026-06-24-analytic-radius-arrow-alignment.txt`
- `../raw/2026-06-24-rc-stage-capacitance-terminology.txt`
- `../raw/2026-06-24-default-m8x20x1-washer-geometry.txt`
- `../raw/2026-06-24-stage-resistance-length-correction.txt`
- `../raw/2026-06-25-melf-0207-resistor-chain-candidate.txt`
- `../raw/2026-06-25-melf-direct-stage-controls.txt`
- `../raw/2026-06-25-slide-simulation-result-source-and-breakdown-scale.txt`
- `../raw/2026-06-25-melf-default-merge-and-resistor-stress-correction.txt`

## Decisions

- Use a Git repository structured for AI collaboration.
- Include `AGENT.md` guidance at each directory level.
- Preserve raw chats and summarize them into hierarchical markdown knowledge.
- Include a web-based presentation section.
- Treat LEGEND-style SHV bias filtering as the initial use case while keeping the design adaptable.

## Core Design

The filter is an axisymmetric stack of alternating HV and ground plates. The HV path includes a large central resistance. The capacitive sections use dielectric-filled plate overlap regions, while non-overlap regions may use lower-permittivity material to reduce unwanted capacitance.

## Open Questions

- Is NiZn ferrite quiet and stable enough as a resistive core?
- What field enhancement occurs at the rounded inner and outer plate edges?
- Does the dielectric boundary need to intrude into the overlap region, or can it end at the overlap edge?
- How much does the outer ground tube change peak field and capacitance?
- What connector strategy is appropriate after the screw-terminal prototype?

## 2026-06-22 Edge-Effect Update

- Concern: capacitor plate edges may raise local electric field, but rounded or foil-like edges should scale more weakly than a needle point.
- Correction: the `1 - z / sqrt(R^2 + z^2)` disk-axis expression assumes uniform surface charge, while the filter plates are closer to constant-potential conductors.
- Working approximation: use the nearest opposite-conductor clearance, then evaluate both local conducting-cylinder-over-plane and equal-clearance surrounding-ground limits for web-interface screening; treat it as triage only.
- Interpretation: this is plausibly conservative because it replaces open fringe space with closer/larger grounded boundaries, but that is more like a capacitance or field-energy argument than a proven pointwise peak-field bound.
- Additional bound idea: a ball of radius equal to the edge radius inside an equal-clearance grounded sphere gives a very conservative analytic envelope; stretching that ball into a disk while maintaining or increasing ground distance should smear charge and reduce peak field.
- Web UI change: specify rounded edge by diameter as a percentage of plate thickness; derive radius internally for geometry and field estimates.
- FEA follow-up: start with analytic benchmark geometries including parallel plates, coaxial cylinders, cylinder over plane, cylinder inside a grounded shell, sphere inside a grounded shell, conducting disks, and rounded wedge/edge cases.
- Durable note: `docs/knowledge/edge-effects.md`.
- Follow-up: calibrate or replace the approximation with axisymmetric FEA when simulation work resumes.

## 2026-06-22 RC-Network Update

- Need: estimate the ladder stage formed by capacitance from each bias plate to ground and resistance between adjacent bias plates.
- Added web estimates for one-gap HV-ground capacitance, per-stage bias-node capacitance to the two adjacent ground plates, adjacent bias-to-bias parasitic capacitance, parasitic-to-stage-capacitance ratio, adjacent bias resistance, and RC corner frequency.
- Working approximation: use parallel-plate capacitance for washer overlap and for parasitic capacitance through the core material plus epoxy around the core inside the ground-plate inner diameter.
- High-frequency concern: `C_parasitic / C_g_stage` sets a capacitive feedthrough divider when the resistor no longer dominates.
- Durable note: `docs/knowledge/rc-network.md`.

## 2026-06-22 Material/Assembly Update

- Candidate washer dielectric: alumina is now the preferred Prototype 0 target because the RC corner is already comfortably below 50 Hz with obtainable geometry. FR4/G10 remains the fallback if alumina washers cannot be sourced or machined.
- Candidate potting compound: MG Chemicals 9510 One-Part Epoxy Potting Compound, Heat Cure.
- Candidate resistive core: Fair-Rite type 61 NiZn ferrite, first tested as 4 mm, 5 mm, and 6 mm diameter cut-and-polished discs.
- Candidate contact method: conductive epoxy between ferrite discs and bias plates, with spacers holding the stack geometry during bonding and potting.
- Candidate void-control process: fill with epoxy, then use repeated vacuum and nitrogen-pressure cycles before heat cure.
- Web UI changes: added a washer material preset menu and a `C vs FR4` metric. Alumina now uses `epsr = 10` as the default washer value, while FR4/G10 remains available at `epsr = 4.4`. Also corrected the core controls so they are generic `Core material` plus internal `Conductor epsr`, displayed as `Conductor &epsilon;<sub>r</sub>`, with Type 61 only one selectable preset.
- Piezoelectric or ferroelectric high-permittivity washer dielectrics are now screening-only / likely no-go because microphonics could couple into the detector-bias path.
- Alumina PD interpretation: dense alumina is a sensible low-PD-risk ceramic, but the likely discharge initiators are interface voids, epoxy bubbles, chipped washer edges, cracks, contamination, and sharp conductor features rather than the nominal alumina bulk alone.
- Key risks to measure: ferrite noise and voltage coefficient, surface leakage after cutting/polishing, conductive-epoxy contact resistance and squeeze-out, trapped voids or partial discharge, cure/shrinkage stress, and dielectric loss/leakage/microphonics for any non-alumina high-permittivity washer candidate.
- Durable notes: `docs/knowledge/materials.md`, `hardware/materials/resistive-core.md`, and `hardware/prototypes/prototype-0.md`.

## 2026-06-23 Raw-Record Update

- Added a reconstructed raw conversation record for the web/materials/edge/RC continuation.
- Important caveat: the raw continuation omits tool logs and routine intermediate steps, and some turns respond to partially finished browser/app work. Readers should expect some apparent non sequiturs.
- Instruction strengthened: future substantive sessions should update `docs/chats/raw/` before closing, even when work remains in progress.

## 2026-06-23 Pi FEA Backend Update

- The web app should keep live approximations and quick screening in browser JavaScript.
- The `Solve field` button is now shaped to try a future `/api/field-solve` backend first, then fall back to the local JavaScript finite-difference solver if no backend is present.
- Multi-client backend rule: the Pi server should use per-solve job IDs and per-job results, not shared `latest-*` output files, so separate tabs or users cannot overwrite or receive each other's solves.
- Durable note: `docs/knowledge/pi-fea-backend.md`.

## 2026-06-23 Gap-Control Update

- Web geometry controls now use radial gaps for dependent dimensions: core-to-ground gap and HV-to-tube gap.
- Ground plate outside diameter is derived as equal to tube inside diameter.
- Derived dimensions still populate the legacy parameter names used by the solver and CAD/field drawing code.
- Durable note: `docs/knowledge/geometry.md`.

## 2026-06-23 Breakdown-Range Update

- Clearance-like web controls now use provisional washer-material dielectric strength to set their slider minimum and 10x design-factor maximum.
- The affected controls are core-to-ground gap, HV-to-tube gap, plate gap, and plate thickness.
- Custom and generic high-K screening presets use a fixed `0.4 mm` to `4 mm` range.
- These ranges are early screening constraints only; real hardware needs datasheets, measured coupons, and interface/void/edge assessment.
- Durable notes: `docs/knowledge/materials.md` and `docs/knowledge/design-requirements.md`.

## 2026-06-23 Permittivity/Epoxy UI Update

- The visible web UI now displays relative permittivity as `&epsilon;<sub>r</sub>` instead of `epsr`.
- Internal field names keep the ASCII `epsr` suffix for JSON, JavaScript, Python, and future API compatibility.
- The epoxy region now has an `Epoxy material` dropdown. MG Chemicals 9510 is the selected first candidate, not the generic label for the whole epoxy control.

## 2026-06-23 Slide Graphics Update

- The Slides tab now uses live generated graphics from the current designer parameters.
- Added slide canvases for the CAD cutaway, r-z geometry half-section, material-region callouts, rounded-edge screening, and RC ladder estimates.
- The drawing functions were generalized so the same design state can render to both the designer canvases and the presentation canvases.

## 2026-06-23 Radial Gap Label Clarification

- Confirmed the core-ground and HV-tube gap controls are radial surface-to-surface clearances, not diameter deltas.
- The derived diameters use the expected factor of 2: ground ID equals core OD plus twice the core-ground gap, and HV OD equals tube ID minus twice the HV-tube gap.
- Updated the web labels to say radial for those clearances and axial for the plate gap.
- Fixed the 2D r-z geometry and field canvases to use an equal mm-to-pixel scale in the axial and radial directions, so equal axial/radial dimensions look equal on screen.

## 2026-06-23 JavaScript Solver Clarification

- Confirmed the current in-browser `solveField` path is a structured-grid finite-difference / finite-volume-style relaxation solver, not real FEA.
- The metric formerly labeled `Iterations` is now labeled `Solver sweeps`; for the JavaScript fallback it means full Gauss-Seidel relaxation passes over the structured r-z grid.
- Added detailed code comments explaining the grid construction, conductor sampling, boundary conditions, relaxation stencil, field extraction, and limitations.
- Fixed the JavaScript fallback sweep count so reaching the configured sweep limit reports the actual number of sweeps instead of one too many.
- The browser fallback grid is now locally refined around rounded plate-edge fillets. The injected corner coordinates keep local spacing no larger than one tenth of the physical rounded-edge radius while avoiding that spacing throughout the whole bulk volume.
- The browser fallback now also performs one field-driven adaptive refinement pass: a probe solve locates high-field dielectric nodes, midpoint coordinates are inserted around those regions, and the final solve is seeded from the probe voltage.

## 2026-06-23 Core Resistivity Update

- The web app now specifies core volume resistivity with a log-scale slider in ohm-cm instead of directly specifying total core resistance.
- Total core resistance is derived from `R = rho L / A` using the current stack length and core cross-sectional area.
- Adjacent bias-to-bias stage resistance is derived from the same resistivity and the HV-to-HV pitch.
- Fair-Rite type 61 and generic NiZn presets default to `1e8 ohm-cm`; the derived total core resistance remains as a readout and legacy parameter.

## 2026-06-23 Pi Backend Scaffold

- Added `software/bias_filter/field_backend.py`, a dependency-free Python HTTP server for the Pi.
- The server serves the web designer and implements `POST /api/field-solve`, `GET /api/field-solve/{job_id}`, and `GET /api/health`.
- Each solve request receives an independent job ID and writes under a per-job directory, avoiding shared `latest-*` browser outputs.
- The current backend worker uses the repository axisymmetric finite-difference screening solver and reports `source = fea-backend-axisymmetric-fd`; it is structured so a stronger FEA worker can replace that solve step later.
- Backend results now include a symmetry plan. Future FEA should generally use an exact mirrored half-stack solve, while `full_stack` remains the validation/browser-compatible fallback.
- The repeated-cell approximation was dropped from the backend plan. If a smaller representative calculation is desired, the user can set the web UI to two plate pairs explicitly.
- The mirror-half code path must be checked against a same-geometry full-stack solve before use. This is a code/regression check, not a physics approximation check.
- Future FEA should use adaptive meshing or explicit local refinement. Rounded plate edges, dielectric-boundary endpoints, and tube-facing high-field regions need much finer elements than the bulk, with mesh convergence recorded for peak field and peak location.

## 2026-06-23 Dielectric Margin Update

- The web field solve was extended to report maximum sampled electric field by dielectric region and show margin as `E_breakdown / E_max` where a selected material has a placeholder strength.
- Washer presets reuse the existing provisional dielectric-strength values; epoxy presets use a conservative placeholder of `15 kV/mm` until MG 9510/current datasheet or coupon values are entered.
- A follow-up correction removed the separate core-adjacent margin bucket because the central resistive/conductive path is an equipotential conductor for electrostatic field screening.

## 2026-06-23 Conductive-Core Field Region Correction

- Corrected the dielectric-margin interpretation: the actual core is conductive/resistive and is an equipotential HV body for electrostatic field screening.
- The core-to-ground free dielectric gap is epoxy/fill, so its peak field and breakdown margin now roll into the epoxy bucket.
- The web and Python screening solvers now use epoxy relative permittivity for solved dielectric nodes between the conductive core surface and the ground-plate inner radius.
- The UI no longer shows a separate core breakdown readout or core-adjacent dielectric margin.

## 2026-06-23 Default Geometry Update

- Default plate pairs changed from 3 to 2.
- Default edge diameter remains 100%, which corresponds to edge radius equal to half the plate thickness.
- Browser defaults, repository JSON defaults, backend fallback defaults, and the RC-network note were kept consistent.

## 2026-06-24 Single-Stage RC Drawing Update

- The slide RC ladder graphic now shows one stage only: two bias nodes, one series stage resistor, two shunt capacitances to ground, and one parasitic capacitance between the two bias nodes.
- Removed the visual continuation that previously showed a second resistor and third shunt capacitor.

## 2026-06-24 Analytic Radius Arrow Update

- Moved the analytic-check edge-radius double arrow onto the fillet-circle centerline so it runs from the circle center to the rim instead of floating above the radius.

## 2026-06-24 RC Stage Terminology Update

- Clarified that `Gap C` is one HV-ground physical gap, while `Stage Cg` is the capacitance from one bias plate to its two adjacent ground plates.
- The attenuation plot uses `Stage Cg = 2 * Gap C`, `Stage R`, and `Stage Cpar`.
- `Stage Cpar` is estimated from capacitance through the core material plus the epoxy around the core between adjacent bias plates.

## 2026-06-24 Default M8x20x1 Washer Geometry

- Updated defaults to match an easily sourced alumina M8x20x1 washer: 8.2 mm ID, 20 mm OD, 1 mm thickness.
- Kept the web inputs unchanged; the existing gap controls now default to core-ground radial gap 2.1 mm, HV-tube radial gap 2 mm, plate gap 1 mm, and tube ID 24 mm.
- The derived default geometry is ground ID 8.2 mm, HV OD 20 mm, and ground OD/tube ID 24 mm.

## 2026-06-24 Stage Resistance Correction

- Corrected `Stage R` to use the face-to-face adjacent-bias separation through gap + ground plate + gap.
- For the 1 mm gap / 1 mm plate default, the stage resistance length is 3 mm, not the 4 mm HV-center-to-HV-center pitch.
- The default `Stage R` is now about 239 Mohm for a 4 mm core OD and `1e8 ohm-cm` core resistivity.

## 2026-06-24 Current Corrections

This historical summary includes earlier intermediate defaults. The current design state is captured in `2026-06-24-current-handoff.md`; key corrections are:

- Default core OD is now 2 mm, not 4 mm.
- HV OD is the editable outer radial control with a 12 mm minimum. Tube ID and ground plate OD are derived from `HV OD + 2 * HV-tube radial gap`.
- Current default derived geometry is core OD 2 mm, ground ID 6.2 mm, HV OD 20 mm, and tube ID / ground OD 24 mm.
- The designer labels the axial gap as washer thickness and the conductor thickness as plate thickness.
- The web UI reports `Supported Emax` plus the raw point maximum diagnostic, rather than using a single raw point maximum as the headline result.
- FEniCSx is implemented and installed on the Pi, but the deployed service still defaults to FD for ordinary jobs. Use `FEniCSx required` for the conforming solver.
- Field solvers and cutaway views use flat washer slabs only between adjacent plate faces. Epoxy fills rounded-edge pockets and other non-washer voids. The capacitance estimate still uses the simpler washer-overlap approximation.

## 2026-06-25 MELF 0207 Resistor Chain Candidate

- A resistor-chain alternate is now under consideration using a Vishay Beyschlag professional MMB 0207 MELF part around 10 Mohm per resistor.
- The exact typed order code `MMB0207MC1005FB200` did not resolve directly; verify the part number before ordering. The official Vishay ordering grammar suggests a likely 10 Mohm, 50 ppm/K, 1%, B2-code part is close to `MMB02070C1005FB200`.
- Datasheet-screening limits: MMB 0207 reaches 15 Mohm, 10 Mohm is in the 50 ppm/K 1% range, rated operating voltage is 350 V AC RMS/DC per resistor, and body size is about 5.8 mm by 2.2 mm.
- The `MMB0207 10M MELF` web preset is one 10 Mohm direct stage with `Stage Cpar = 0.3 pF`. The 240 Mohm value is only a deliberate chain scenario or the potted MELF-chain preset.
- Important correction: do not size this resistor option as if full 6 kV DC appears across it in normal operation. The detector load is sub-nA, so resistor drop is `I * R`; see `docs/knowledge/resistor-voltage-stress.md`.
- This option should later be modeled as a physical resistor or routed discrete resistor chain because end caps, joints, folded turns, potting interfaces, pulse behavior, and distributed capacitance may dominate the field and parasitic behavior.

## 2026-06-25 MELF Direct Stage Controls

- The RC ladder method is now controlled by a separate `Direct stage RC inputs` checkbox rather than being permanently tied to MELF material selection.
- When direct stage mode is active, the web app shows direct `Direct stage R` and `Direct stage Cpar` controls while hiding the bulk resistivity and conductor-epsilon controls.
- Ferrite-like presets still derive `Stage R` from `rho L/A` and `Stage Cpar` from the simple core-plus-epoxy parallel-plate approximation.
- Selecting a MELF preset checks direct stage mode by default. The default MMB0207 MELF stage is `10 Mohm` and `0.3 pF`; the potted MELF-chain preset uses `240 Mohm` and `0.5 pF`.

## 2026-06-25 Slide Simulation Result Source And Breakdown Scale

- The Slides tab Simulation Results graphic now uses the latest actual solved field result when it matches the current design parameters.
- If no matching solve exists after parameter changes, the slide falls back to a reduced browser JS preview and labels that explicitly.
- The slide includes a source blurb identifying whether it is showing Browser JS, backend adaptive FD, backend FEniCSx, or preview output.
- Field-map colors now normalize dielectric cells by their material breakdown value where available, giving washer and epoxy separate breakdown-relative color behavior.
- The colorbar maximum is the highest available dielectric breakdown field and includes marker lines for the dielectric breakdown values, including the lower-breakdown material.

## 2026-06-25 MELF Default Merge And Resistor Stress Correction

- Merged the other chat's MELF default: the `MMB0207 10M MELF` direct stage uses `10 Mohm` and `0.3 pF`, while the potted MELF-chain preset remains `240 Mohm` and `0.5 pF`.
- Aligned the default JSON and backend fallback to `melf_stage_resistance_log10_ohm = 7.0`.
- Added `docs/knowledge/resistor-voltage-stress.md` and a root `AGENT.md` guardrail.
- Key correction: do not size the MELF resistor path as if it must hold the full 6 kV DC bias in normal operation. The steady drop is `I * R` at sub-nA detector current; full-bias breakdown is a dielectric/spacing and capacitive pulse-energy issue.

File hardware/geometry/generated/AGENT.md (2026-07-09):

# Agent Guide: hardware/geometry/generated

This directory contains generated geometry artifacts from `software/bias_filter/axisymmetric_model.py`.

Do not hand-edit generated `.scad`, `.obj`, `.mtl`, or `.stl` files. Update `hardware/geometry/default-parameters.json` or the generator script, then regenerate.

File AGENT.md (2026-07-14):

# Agent Guide: Discoidal Capacitor Bias Filter

This repository is intended to be readable and useful to AI coding, documentation, simulation, and design agents.

## Project Purpose

Develop a high-voltage, low-current detector bias filter based on a discoidal capacitor stack. The geometry and electrical analysis are connector-independent. A later implementation is expected to serve SHV connector inputs, with an initial practical voltage ceiling near 6 kV, but SHV packaging is not part of the current model. Detector bias currents are expected to be sub-nA.

## Design Summary

The core concept is a cylindrical filter with alternating discoidal capacitor plates and a central resistive element:

- High-voltage plates connect to the center bias path.
- Ground plates are annular and couple to outer ground structure.
- The central core is a large resistance, approximately 100 Mohm to low Gohm.
- Plate edges are rounded to control electric-field enhancement.
- Dielectric choices matter: high permittivity is useful in the HV-to-ground overlap region, while lower permittivity is preferred around the resistive core and possibly the outer fringe region.
- Early prototypes may use NiZn ferrite as both structure and resistive element, but MELF resistor chains remain a likely alternate path if ferrite noise or stability is unacceptable.

## Working Rules

- Preserve raw collaboration records in `docs/chats/raw/`.
- Before ending a substantive session, update `docs/chats/raw/` with the user-facing conversation record or a clearly labeled reconstruction. Tool logs and routine intermediate steps are not required.
- Put distilled, durable knowledge in `docs/knowledge/`.
- Keep assumptions explicit, especially around dielectric properties, resistance, breakdown limits, connector ratings, and simulation boundaries.
- If resistor voltage stress comes up, read `docs/knowledge/resistor-voltage-stress.md` first; do not assume the bias resistor must withstand the full 6 kV DC supply in normal sub-nA operation.
- Prefer axisymmetric models when the geometry allows it.
- Treat values as provisional unless backed by calculation, datasheet, measurement, or simulation.
- When changing design intent, update both the relevant knowledge note and any affected presentation material.
- For a Raspberry Pi explicitly designated as a dedicated AI development device, treat full remote administration as intentional. `NOPASSWD` sudo, package installation, service changes, and reboots are normal in-scope development operations and do not require repeated user confirmation. Keep durable work in Git or off-device storage because reimaging the microSD card is the recovery boundary. Do not extend this assumption to shared or production hosts.

## Important Parameters

- Core outside diameter.
- Tube inside diameter and ground plate outside diameter.
- HV plate outside diameter.
- Plate gap.
- Plate thickness.
- Edge radius, usually assumed to be half the plate thickness unless specified.
- Dielectric permittivity between overlapping plates.
- Dielectric permittivity outside the overlap region.
- Dielectric permittivity near the central core.

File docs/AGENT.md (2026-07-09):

# Agent Guide: docs

Use this directory for project documentation.

- `knowledge/` contains curated, stable markdown notes.
- `chats/` contains raw and summarized AI collaboration records.

When adding documentation, keep exploratory material separate from settled knowledge. Link summaries back to raw records when possible.

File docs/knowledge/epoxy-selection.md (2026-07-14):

# Potting epoxy selection

## Decision context

The fill must wet copper, alumina, and the resistive core without trapping gas.
For this DC detector-bias application, a datasheet dielectric-strength number is
not enough: small voids or a weak interface can become partial-discharge sites
even when the bulk material is well below its coupon breakdown field.

MG Chemicals 9510 remains the mechanically modeled baseline, but its rigid
cure and large CTE mismatch make lower-modulus materials worth testing. No
one-part, low-viscosity, genuinely low-stress heat-cure epoxy with a complete
public property set was found. Parker CoolTherm ES-21 is one-part, but its
35,000 cP viscosity, Shore D88 hardness, 115 C Tg, and 125 C cure make it a
poor low-stress substitute for 9510.

## Published comparison

Values below are manufacturer datasheet values. Dielectric strength is
converted from V/mil to kV/mm. These are screening values, not guaranteed
partial-discharge inception fields or long-duration DC ratings.

| Material | Working time | Mixed viscosity | Hardness | Tg | Linear CTE below/above Tg | Shrinkage | Dielectric strength | Volume resistivity | Relative permittivity | Practical note |
| --- | ---: | ---: | ---: | ---: | ---: | ---: | ---: | ---: | ---: | --- |
| MG 9510 | Unlimited before heat cure | 4,800 cP | Shore D84 | 70 C | 74 / 217 ppm/C | 3.9%, calculated and undefined basis | 15.75 kV/mm | 2.6e13 ohm-cm | 3.7 at 1 MHz | One-part and easy to degas at leisure, but rigid. Minimum cure is 3 h at 80 C. |
| MG 832FX | 2 h | 700 cP | Shore A88 | 8.8 C | 114 / 218 ppm/C | 2.6%, calculated | 12.99 kV/mm | 5.8e12 ohm-cm | 3.1 at 1 MHz | Best-flowing published MG flexible option; 1:1 mix and 2 min vacuum de-airing at 25 inHg. |
| MG 832FXT | 170 min | 1,920 cP | Shore A80 | 20 C | 124 / 295 ppm/C | 2.4%, calculated | 13.78 kV/mm | 1.5e13 ohm-cm | Lower tensile strength and apparently more compliant; available in 25 mL trial size. |
| MG 832FXC | 170 min | 410 cP | Shore A60 | 12 C | 212 / 260 ppm/C | 2.3%, calculated | 18.58 kV/mm | 1.0e13 ohm-cm | Lowest viscosity and softest listed epoxy; clear cure helps visual void inspection. |
| Epoxies Etc. 20-3241 | 30-45 min | 1,000 cP | Shore A75 | Not published | 50 ppm/C | 0.6% linear | 22.05 kV/mm | 5e15 ohm-cm | Strong published electrical and shrinkage figures and explicit adhesion to ceramics/copper, but short pot life and bulk packaging. |

The 832FXT and 832FXC datasheets do not publish relative permittivity. The web
model provisionally uses 3.1, inherited from the closely related 832FX. That
assumption must be replaced by a supplier value or a cured-coupon measurement
before capacitance predictions are frozen.

## Interpretation

- **Best small prototype:** MG 832FXT because a 25 mL package is available and
  its Shore A80 result indicates much greater compliance than 9510.
- **Best flow and balanced process:** MG 832FX at 700 cP with two hours of
  working time.
- **Best visual void inspection:** clear MG 832FXC. Its 410 cP viscosity should
  also make evacuation and narrow-gap filling easiest.
- **Best published electrical properties:** 20-3241, but its 30-45 minute pot
  life and gallon-scale packaging are significant prototype disadvantages.
- **Current baseline:** 9510 remains useful for comparison and has unlimited
  pre-cure working time, but it should not be assumed mechanically safer merely
  because it has a convenient process.

MG recommends only two minutes at 25 inHg for vacuum de-airing the 832FX
family. A two- to nearly three-hour pot life therefore permits several
mix/degas/fill cycles. Long working time still helps, but unlimited working
time is not necessary for a carefully rehearsed small casting.

Hardness scales are not directly interchangeable: Shore A values for flexible
materials cannot be numerically compared with 9510's Shore D value. More
importantly, hardness is not Young's modulus. The flexible-epoxy datasheets do
not publish the temperature-dependent modulus or viscoelastic data needed for
a defensible thermal-stress FEA, so no modulus is inferred from Shore hardness.

Higher CTE by itself does not mean higher stress. A first-order restrained
thermal stress scales approximately as `E * delta_alpha * delta_T`; a much
lower elastic modulus can outweigh a larger CTE mismatch. Cure shrinkage,
stress relaxation, adhesion, and free-edge stress concentration also matter.

## Glass transition and provisional temperature control

A cured epoxy below its glass-transition temperature is in its relatively
stiff glassy state. Above Tg it is more compliant and viscoelastic, so molecular
segments can rearrange and bonded-in stress can relax through creep. A
cross-linked thermoset does not melt or freely flow above Tg; it remains a
connected solid. Tg is also a broad, time- and frequency-dependent transition,
not a sharp safe/unsafe boundary.

The low Tg values of the 832FX family may be useful rather than inherently
undesirable. At ordinary room temperature, MG 832FX (Tg 8.8 C) and 832FXC
(Tg 12 C) are above their nominal transitions and should be much more compliant
than 9510. MG 832FXT has a nominal Tg of 20 C, so a 20 C environment provides
essentially no transition margin for that material. On cooling through Tg, the
modulus can rise sharply and additional copper/alumina contraction mismatch can
become more strongly locked into stress.

For a flexible-epoxy prototype, use **20 C as a provisional absolute minimum**
for operation, storage, and transport, with **25 C or warmer preferred** until
bonded coupons establish a lower qualified limit. This requirement is practical
for the intended controlled environment, but it must include unpowered storage
and shipping rather than operation alone. A candidate should be cycled with
dwells at 25, 20, 10, 0, and -10 C while monitoring adhesion, leakage,
capacitance, and discharge pulses. For 832FXT in particular, 25 C is the more
credible provisional minimum because its nominal Tg is already 20 C.

## Qualification plan

Cast representative copper/alumina ring coupons using the actual cleaning,
surface preparation, vacuum process, cure schedule, and cool-down rate. For
each candidate:

1. Record mixed viscosity, elapsed process time, vacuum pressure, bubble
   behavior, cure schedule, and visual void count.
2. Measure capacitance and leakage before and after cure.
3. Thermal-cycle coupons through 25, 20, 10, 0, and -10 C while inspecting for
   interface whitening, cracks, delamination, leakage steps, and capacitance
   changes.
4. Perform stepped DC partial-discharge/current-pulse testing with the intended
   voltage polarity and a conservative dwell time.
5. Section sacrificial samples to check wetting at conductor edges and alumina
   interfaces.

Silicone encapsulants such as NuSil R-2188 (Shore A20) and Wacker ELASTOSIL
RT 601 (Shore A45) offer substantially more compliance and long working times.
They are useful fallback candidates, but they are not epoxy presets because
their adhesion, gas permeability, surface contamination, and rework behavior
need a separate design assessment.

## Thermal-model boundary

The current closed-form calculation and FEniCSx thermal model contain MG 9510
properties only. Selecting another epoxy changes electrical permittivity and
dielectric-strength screening, but it does not make the 9510 mechanical model
valid for that material. The thermal backend therefore remains restricted to
9510 until a candidate has credible modulus, Poisson-ratio, CTE, cure-reference,
and strength/interface data. A flexible candidate should first be compared by
coupon testing; a later FEA can add measured temperature-dependent or
viscoelastic properties.

## Primary sources

- [MG Chemicals 9510 TDS](https://mgchemicals.com/downloads/tds/tds-9510.pdf)
- [MG Chemicals 832FX TDS](https://mgchemicals.com/downloads/tds/tds-832fx-2parts.pdf)
- [MG Chemicals 832FXT TDS](https://mgchemicals.com/downloads/tds/tds-832fxt-2parts.pdf)
- [MG Chemicals 832FXC TDS](https://mgchemicals.com/downloads/tds/tds-832fxc-2parts.pdf)
- [Epoxies Etc. 20-3241 TDS](https://products.meridianadhesives.com/storage/downloads/1w7pjlbshwq9myufxb7kysdbnce7gahf/20-3241r-rev062025.pdf)
- [Parker CoolTherm ES-21 TDS](https://www.parker.com/content/dam/Parker-com/Literature/Assembly---Protection-Solutions-Division/Technical-Datasheets-%28TDS%29/Datasheet---CoolThermES-21_DS3623.pd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)
- [NuSil R-2188 product page](https://www.nusil.com/us/en/product/27944394/r-2188silicone-potting-and-encapsulating-elastomer)
- [Wacker ELASTOSIL RT 601 TDS](https://www.wacker.com/h/en-us/medias/ELASTOSIL-RT-601-AB-en-2020.02.10.pdf)

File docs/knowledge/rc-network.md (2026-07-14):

# RC Network Estimate

## Purpose

The plate stack is an RC ladder. Each bias plate node sees capacitance to ground through the high-permittivity washer overlap, resistance to neighboring bias plates through the central resistive element, and unwanted parasitic capacitance to neighboring bias plates through the core material plus epoxy around the core.

The input and inter-stage bias resistances are high-value controls expressed in Mohm. The output series resistance is a separate ohm-valued control because the normal readout-side value is 50 ohms; the web app defaults it to 50 ohms and passes that value to both the browser and backend SPICE models without a megaohm conversion.

Manual numeric entries accept case-sensitive engineering prefixes with or without a space or trailing unit text: `T`, `G`, `M`, `k`, `m`, `u`/`µ`, `n`, `p`, and `f`. Thus `100M`, `100 M`, and `100 MOhm` all enter 100 Mohm in a resistance control, while `100f` enters 100 fF in a capacitance control. A value without a prefix remains in the control's displayed unit.

At high frequency, the resistor no longer sets the divider by itself. The ratio of bias-to-bias parasitic capacitance to bias-to-ground capacitance becomes an important feedthrough estimate.

## Web Estimates

The web interface uses simple parallel-plate formulas. These are first-pass circuit estimates, not field-extracted capacitances.

Single adjacent HV-ground gap capacitance:

```text
r_overlap_inner = max(washer_id, ground_plate_id) / 2
r_overlap_outer = min(washer_od, bias_plate_od) / 2
C_gap ~= epsilon0 epsr_washer pi (r_overlap_outer^2 - r_overlap_inner^2) / plate_gap
```

The washer is treated as a flat annular slab in the axial gaps between plate
faces. The entered washer ID and OD are the primary dielectric dimensions;
selected relation modes derive the ground plate ID and bias plate OD from them.
If a smaller Custom-mode washer is selected, the newly
exposed radial pockets are potting epoxy instead of washer dielectric. If a
larger custom washer is selected, only the portion overlapping both electrodes
contributes to the rough bias-to-ground capacitance estimate.

Single-stage bias-node capacitance to ground:

```text
C_g_stage ~= 2 C_gap
```

This is the capacitance from one bias plate to its two adjacent ground plates. It assumes the bias plate is between two ground plates, which is true for the interior bias nodes in the current stack.

Total two-terminal capacitance estimate:

```text
C_g_total ~= 2 N_pairs C_gap
```

This is the browser estimate for the capacitance from all HV plates/core to the grounded plates/tube when the whole HV conductor set is treated as one terminal. After a FEniCSx solve, the designer readout prefers the energy-extracted value:

```text
C_fea = 2 U / V^2
U = 1/2 integral 2 pi r epsilon0 epsilonr |grad V|^2 dr dz
```

Adjacent bias-to-bias parasitic capacitance:

```text
d_hv_hv ~= plate_thickness + 2 plate_gap
C_parasitic ~= epsilon0 (epsr_core A_core + epsr_epoxy A_core_epoxy) / d_hv_hv
```

where:

```text
A_core = pi r_core^2
A_core_epoxy = pi (r_ground_inner^2 - r_core^2)
```

For ferrite-like bulk cores, `epsr_core` is the selected core permittivity. For MELF 0204/0207 presets, direct stage resistance remains a direct resistor value, but `Cpar` is no longer a fixed package placeholder. The app models the MELF body as a ceramic substrate with a metal-film fill-factor correction:

```text
epsr_core = epsr_substrate / (1 - FF)
```

The default 0207 model uses `epsr_substrate = 9.8` and `FF = 0.50`, giving `epsr_core = 19.6`. This is a first-draft effective-medium approximation for a high-value spiral-trimmed metal-film resistor. It avoids pretending the proprietary film path is known while still letting the capacitance scale with geometry. The old direct `Resistor Cpar` input remains available for non-MELF direct-stage models such as a deliberately lumped potted resistor chain.

After a matching FEniCSx solve, the Designer tab also reports `FEA Cpar`. This is a separate local three-bias-plate energy-difference estimate, not a value extracted from the all-HV total-capacitance solve:

```text
Cpar_adjacent ~= (C_middle_to_all_zero - C_all_bias_to_ground / 3) / 2
```

The division by two accounts for the middle bias plate coupling to two adjacent bias plates in the local model. Treat it as a sanity check until a full capacitance-matrix charge extraction is implemented.

The presentation separates these two capacitance checks. The total-capacitance slide compares washer-overlap `Cg,total` with the all-bias FEA energy integral. A dedicated Cpar slide shows the three excitation geometries used in the polarization difference: middle bias only, both neighbors only, and all three bias plates driven. It also states the expected direction of the analytic error: the axial `epsilon A/d` estimate generally runs high because it assigns core/epoxy flux directly to the neighboring bias plate without fully representing interception by the intervening grounded annulus.

Resistance between adjacent bias plates:

```text
A_core = pi r_core^2
R_total ~= rho_core stack_length / A_core
R_stage ~= rho_core (plate_thickness + 2 plate_gap) / A_core
```

`R_stage` uses the face-to-face bias-plate separation through the intervening gap, ground plate, and second gap. It intentionally excludes the bias-plate thickness because that section is shorted to the bias node.

In the web app, `rho_core` is entered in ohm-cm while geometry is in mm, so the implementation converts `L/A` as `(length_mm / 10) / (area_mm2 / 100)`.

When `Direct stage RC inputs` is enabled, the app instead shows a direct `Direct stage R` input. The total core-chain readout is then the entered stage resistance times the number of adjacent-bias stages, rather than a bulk-resistivity calculation from core geometry.

Stage corner estimate:

```text
f_stage ~= 1 / (2 pi R_stage C_g_stage)
```

High-frequency capacitive feedthrough indicator:

```text
feedthrough ~= C_parasitic / C_g_stage
```

Parasitic reactance takeover point:

```text
f_parasitic ~= 1 / (2 pi R_stage C_parasitic)
```

This marks the frequency where the adjacent-bias parasitic capacitance has the same reactance magnitude as the adjacent-bias ohmic path. Above this point, the resistor is no longer the dominant bias-to-bias path for AC noise, and the parasitic capacitance increasingly determines feedthrough.

Two-terminal shunt admittance estimate:

```text
G_load = I_load / V_bias
Y(f) = G_load + j 2 pi f C_g_total
```

The designer uses the load-current slider for `I_load`, defaulting to 1 nA. Before an FEA solve, `C_g_total` is the washer-overlap estimate above. After a matching FEniCSx solve, `C_g_total` is the energy-extracted capacitance from the solved geometry.

The web slide plots the ladder transfer as voltage-noise attenuation:

```text
attenuation_dB = -20 log10(|Vout / Vin|)
```

This uses the usual power-dB convention for equal impedances, so a factor-of-10 voltage-noise reduction is shown as 20 dB attenuation.

The displayed attenuation and SPICE-style ladder sweeps are intentionally limited to 1 Hz through 100 MHz. Power-line noise is the low-frequency feature that matters most here, so the plot starts far enough below 50/60 Hz to make the low-frequency rolloff clear without spending much visual space on slower drift. The high end is capped at 100 MHz because the DAQ sample rate is only around 200 MS/s, making higher-frequency response less useful for this design screen.

The designer tab reports the same single-stage attenuation values numerically:

- Attenuation at 50 Hz, calculated from the one-stage divider using `R_stage`, `C_g_stage`, and `C_parasitic`.
- High-frequency attenuation limit, calculated from the `C_parasitic / C_g_stage` feedthrough ratio.

The RC ladder slide also labels the 50 Hz attenuation point on the plotted transfer curve and draws the high-frequency attenuation ceiling implied by that same single-stage `C_parasitic / C_g_stage` ratio.

## Single-section validation and multiplication limit

For one isolated `R_stage`-`C_g_stage` section with no additional end
resistance or external load, the analytical divider and the full MNA/SPICE
solution are exactly the same. With the current default values at 50 Hz, both
give 0.0668998 dB. This is the limiting test that validates the individual
resistance and shunt-capacitance definitions.

That identity does not justify raising the one-section transfer function to a
stage count for the assembled filter. The physical ladder is unbuffered, so
downstream shunt capacitors load upstream nodes. The current section-count
comparison is still more aggressive because it applies the cable and detector
load to every multiplied section and counts every nonzero end resistance as a
full stage. The full ladder applies the external load once at the output.

The SPICE slide also includes a separate **full ladder unloaded** curve. This
retains the input series resistance, every internal stage resistance, every
stage-to-ground capacitance, and every adjacent-stage parasitic capacitance.
It removes load conductance, output-series current, cable, transmission line,
and detector capacitance, then measures voltage at the last filter node with
infinite input impedance. It therefore answers a different question from the
loaded detector curve: how much source voltage noise the filter itself removes
at its bare output terminal. For the default design at 50 Hz, the backend gives
about 0.45 dB unloaded versus 18.16 dB with the specified transmission-line
load.

At 50 Hz with the default loaded design, the multiplied and full-ladder results
diverge with stage count: 36.75 versus 18.16 dB for two bias stages, 73.51
versus 26.76 dB for five, and 134.76 versus 37.22 dB for ten. The apparent
two-to-one dB ratio at two stages is therefore coincidental rather than evidence
that the two washer capacitors were counted twice. Use the full ladder or
backend SPICE/MNA result for design conclusions.

The main loaded-ladder and SPICE slides therefore omit the multiplied-stage
curve. The electrical-model slide uses a one-section curve only to explain how
`R_stage`, `C_g`, and `C_parasitic` shape a single divider. The stage-count
divergence comparison is retained as a backup slide for questions about why the
one-section transfer cannot simply be raised to a power.

Washer dielectric comparison:

```text
C_gain_vs_FR4 ~= epsr_washer / 4.4
```

This is only valid for the simple parallel-plate washer-overlap estimate, but it is useful for estimating how much capacitance a better dielectric buys before sourcing or machining ceramic washers.

With the current browser defaults (`epsr_washer = 10` alumina-like, MELF 0207 direct-stage resistance, `epsr_core = 19.6` effective MELF core, 2.2 mm core OD, two plate pairs, 6.6 mm washer ID, 20 mm washer OD, 1.5 mm washer thickness, and 26 mm tube ID), the estimate is roughly:

- `C_gap`: about 16.5 pF.
- `C_g_stage`: about 33.1 pF per bias plate.
- `C_parasitic`: about 0.26 pF between adjacent bias plates in the analytic/SPICE estimate.
- `FEA Cpar`: about 0.14 pF in the current three-bias FEniCSx smoke test.
- `R_stage`: 12 Mohm for the default 0207 direct stage.

The default capacitance estimates correspond to:

```text
C_gap ~= epsilon0 * 10 * pi * (10^2 - 3.3^2) / 1.5
C_g_stage ~= 2 C_gap
C_parasitic ~= epsilon0 * (19.6 * pi * 1.1^2 + 3.4 * pi * (2.55^2 - 1.1^2)) / 4.5
```

## Assumptions And Gaps

- Edge correction is ignored for capacitance.
- Outer tube capacitance is ignored in the circuit estimate; this is expected to be smaller when the washer overlap has much larger area and permittivity.
- The admittance readout is a quasi-static shunt estimate. It does not yet solve a lossy complex-permittivity FEM problem.
- The parasitic estimate focuses on the selected core/conductor material and epoxy around the core inside the ground-plate inner diameter.
- FR4/G10, alumina, zirconia/ZTA, and high-permittivity electroceramics can differ strongly in loss, leakage, voltage coefficient, microphonics, and practical surface finish; the RC estimate only uses `epsr`.
- A later FEA extraction should separately report washer capacitance to ground, tube/fringe capacitance to ground, and a true capacitance-matrix bias-to-bias parasitic capacitance.

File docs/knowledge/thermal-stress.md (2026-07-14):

# Default-build thermal mismatch analysis

## Result

The default MG Chemicals 9510 / alumina / copper stack cannot be assigned a
credible subzero operating limit from datasheets alone. Two calculations are
kept side by side: a simple differential-contraction baseline and an
axisymmetric thermoelastic FEniCSx model of the bonded geometry.

The closed-form fully restrained baseline predicts that the epoxy-to-alumina
CTE difference controls:

- Stress-free reference: 70 °C, the published glass-transition temperature.
- No cold target is assumed. The saved 20 °C evaluation point represents
  ordinary room-temperature handling, not a design requirement.
- At 20 °C, the nominal full-restraint stress is 15.2 MPa using an assumed
  3.0 GPa epoxy modulus and Poisson ratio 0.35.
- Published cured 9510 tensile strength: 20 MPa.
- Nominal strength margin at 20 °C: 1.32.
- Nominal full-restraint strength crossing: +4.1 °C.
- Modulus sensitivity, 2 to 4 GPa: -28.8 to +20.6 °C.
- If geometry and free edges reduce effective restraint to 50%, the nominal
  crossing moves to -61.7 °C.

Use +4 °C as the conservative closed-form onset-of-risk reference for the
present default geometry, not as a predicted fracture temperature. The broad
restraint and modulus sensitivity means the design has not earned a subzero
rating.

Until bonded-ring coupons establish a qualified cold limit, transport the
assembly at controlled room temperature, preferably at or above 25 °C, and
avoid unheated or freezing shipment. This is interim risk management rather
than a qualified transport-temperature rating.

## Closed-form baseline

Below the epoxy glass transition, the first-order equibiaxial estimate is:

```text
delta_epsilon = abs(alpha_epoxy - alpha_substrate) (Tg - T)
sigma = k E_epoxy delta_epsilon / (1 - nu_epoxy)
```

`k` is the effective restraint factor. `k = 1` is the fully restrained baseline
used for the default comparison. The first tensile-strength crossing is found
by setting `sigma` equal to 20 MPa. This calculation intentionally remains in
the project because it is transparent, fast, and independent of the FEA mesh.

### Basis of the stress equation

The baseline treats the epoxy as an isotropic layer with equal in-plane
principal stresses, `sigma_1 = sigma_2 = sigma`, and zero through-thickness
stress. Under plane stress, the elastic strain in either in-plane direction is

```text
epsilon_elastic = (sigma - nu sigma) / E = sigma (1 - nu) / E
```

Setting that elastic strain equal to the restrained differential thermal
strain gives

```text
sigma = k E delta_epsilon / (1 - nu)
```

This is the origin of the `1 / (1 - nu)` term. It is a uniform equibiaxial
restraint assumption, not a solution of the actual bonded-ring geometry. The
restraint factor `k` is an explicit sensitivity parameter; the FEA replaces
that assumed uniform restraint with displacement compatibility in the modeled
geometry.

The stress-free reference is assumed to be the 9510 glass-transition
temperature, 70 C. The calculation assumes stresses relax above this point and
begin accumulating as the bonded assembly cools below it. That reference is an
engineering assumption, not a measured stress-free temperature for this cure
process.

### Default numerical substitution at 20 C

For the epoxy-to-alumina interface:

```text
alpha_epoxy   = 74.0e-6 /C
alpha_alumina =  8.2e-6 /C
delta_alpha   = 65.8e-6 /C
delta_T       = 70 C - 20 C = 50 C

delta_epsilon = 65.8e-6 * 50 = 0.00329 = 0.329%
sigma         = 1.0 * 3000 MPa * 0.00329 / (1 - 0.35)
              = 15.1846 MPa
strength margin = 20 MPa / 15.1846 MPa = 1.317
```

At the 10 mm washer outer radius, the corresponding free radial mismatch is

```text
delta_r = 0.00329 * 10 mm = 0.0329 mm = 32.9 um
```

For comparison, the epoxy-to-copper calculation uses
`delta_alpha = (74.0 - 16.9)e-6 = 57.1e-6 /C`, giving 13.1769 MPa. Its free
radial mismatch is 37.115 um at the larger 13 mm tube radius. Alumina controls
the stress comparison because stress in this baseline depends on CTE mismatch,
not radius; radius is used only to report the free displacement mismatch.

### Tensile-strength crossing

Solving the stress equation for the temperature drop at the published 20 MPa
cured tensile strength gives

```text
delta_T_failure = strength * (1 - nu) / (k E delta_alpha)
T_onset = 70 C - delta_T_failure
```

For alumina, `E = 3000 MPa`, `nu = 0.35`, and `k = 1`:

```text
delta_T_failure = 20 * 0.65 / (1.0 * 3000 * 65.8e-6)
                = 65.8561 C
T_onset         = 70 - 65.8561 = 4.1439 C
```

The same calculation gives the documented sensitivity values:

| Assumption | Calculated onset |
| --- | ---: |
| `E = 2 GPa`, `k = 1` | -28.784 C |
| `E = 3 GPa`, `k = 1` | +4.144 C |
| `E = 4 GPa`, `k = 1` | +20.608 C |
| `E = 3 GPa`, `k = 0.5` | -61.712 C |

These crossings compare a calculated bulk epoxy stress with the published bulk
tensile strength. They are reference points, not predictions of interface
debonding or fracture temperature.

The checked-in executable calculation and complete numeric output are:

- `software/bias_filter/thermal_stress.py`
- `simulations/thermal/outputs/default-thermal-stress.json`

## Axisymmetric thermal FEA

`software/bias_filter/thermal_fenicsx_solver.py` meshes the complete bonded
solid r-z half-section rather than the dielectric-only electrostatic domain.
It solves copper, alumina, epoxy, and the core using small-strain axisymmetric
linear elasticity. Cylindrical symmetry and the axial center-plane mirror
symmetry are exact for the idealized uniform stack. Exposed surfaces are
traction-free and all material interfaces are perfectly bonded.

The default 0.30 mm thermal mesh at 20 C has 9,005 cells and reports 32.175 MPa
for the 99th percentile of epoxy cell-center maximum-principal tensile stress.
The raw material-corner peak is 53.254 MPa. Refining the target size to 0.20 mm
gives 21,006 cells, 32.115 MPa P99, and a 61.985 MPa raw peak. P99 changes by
only 0.19%, while the raw corner peak changes by 16.4%. Use P99 for design
comparison and retain the raw value only as a mesh-sensitive diagnostic.

The solve uses 70 C as the stress-free reference and applies a uniform
temperature change. The Designer's thermal mesh control sets the Gmsh target
element size; **Solve thermal FEA** calls `POST /api/thermal-solve` on the Pi
backend. Because this is a linear thermoelastic model, the presentation curve
scales the solved P99 result linearly with temperature difference.

The Designer viewer includes a **Thermal FEA** tab. The backend returns the
cell-center epoxy maximum-principal tensile stress from the solved half-stack;
the browser mirrors those points about the exact center plane to display the
complete stack. The color scale is capped at P99 so the bulk stress pattern
remains visible, while the raw mesh-sensitive peak is marked separately. The
default 0.30 mm solve returns 2,362 epoxy cell points in a roughly 75 kB JSON
response.

The adjacent **FEA model regions** tab is not a literal geometric half-section.
It shows representative r-z material regions used by the cylindrically
symmetric FEA models; individual electrostatic solve regions may be reduced by
the selected exact-mirror or repeating-interior strategy.

The FEA does not include cure shrinkage, temperature-dependent properties,
viscoelastic stress relaxation, plasticity, voids, cohesive interfaces,
debonding, or fracture. It is a geometry-aware elastic comparison rather than
a mechanical qualification or failure prediction.

## Alternative potting materials

The candidate comparison and primary datasheets are recorded in
`docs/knowledge/epoxy-selection.md`. Flexible MG 832FX-family epoxies and
Epoxies Etc. 20-3241 may reduce bond stress, but their public datasheets do not
provide enough mechanical information to substitute them directly into this
FEA. Shore hardness is not Young's modulus and is not converted into one.

For a first-order comparison, restrained thermal stress scales as

```text
stress scale ~ E_epoxy * abs(alpha_epoxy - alpha_substrate) * delta_T
```

Consequently, a flexible epoxy can produce less stress than 9510 even if its
CTE mismatch is larger. The result depends on its much lower modulus,
temperature-dependent viscoelastic relaxation, cure shrinkage, and adhesion.
Those quantities need supplier data or measurements. Until then, the web
thermal solve is intentionally limited to MG 9510; other presets are valid for
electrical sensitivity studies only.

The low glass-transition temperatures of the flexible candidates change the
physical interpretation. Above Tg a cross-linked epoxy remains solid but is
more rubbery and viscoelastic, allowing creep and stress relaxation. Below Tg
it becomes glassier and stiffer, so contraction mismatch is more readily stored
as elastic stress. The transition is broad and rate-dependent. A provisional
flexible-epoxy build requirement is therefore a 20 C absolute minimum and a
preferred controlled minimum of 25 C for operation, unpowered storage, and
transport until coupons qualify lower temperatures. This gives some margin
above the 8.8 C Tg of 832FX and 12 C Tg of 832FXC, but little or no margin above
the 20 C Tg of 832FXT; 832FXT should be treated as a 25 C-minimum candidate at
this stage.

## Data and assumptions

- MG Chemicals 9510: cure 3 h at 80 °C (minimum-temperature schedule), Tg
  70 °C, pre-Tg CTE 74 ppm/°C, cured tensile strength 20 MPa, lap shear 9.2 MPa
  on stainless and 5.8 MPa on aluminum, and bulk service range -65 to 150 °C.
- The same TDS, version 5.2 dated 23 January 2026, page 2, lists
  `Shrinkage 3.9% Calculated` in its Liquid Properties table. It does not define
  whether this is linear, volumetric, mass-based, or referenced to a particular
  cure/gel state. Page 3 separately reports 3.9% weight loss at 155 °C after
  600 hours; that is a different property despite the identical number.
- CoorsTek AD-96 alumina: CTE 8.2 ppm/°C and elastic modulus 303 GPa.
- C110 copper: CTE 16.9 ppm/°C.
- 9510 elastic modulus and Poisson ratio are not published. The model preserves
  an assumed 2 to 4 GPa modulus range, 3 GPa nominal, and Poisson ratio 0.35.

The TDS shrinkage entry is not added as 3.9% elastic strain. The manufacturer
does not publish its definition or the post-gel locked-in fraction, and the
assembly's cure restraint and stress relaxation are unknown. Existing project
phrases such as “liquid-to-cured shrinkage” are interpretations rather than TDS
wording. This provenance/definition issue is a priority follow-up; until it is
resolved, the thermal analysis must not claim to include residual cure stress.

The manufacturer's -65 °C service floor describes the cured bulk material; it
does not qualify a bonded copper/alumina assembly. Interface pull-off strength,
fracture toughness, residual cure stress, voids, edge relief, and thermal-cycle
fatigue remain unmodeled.

## Qualification action

Build representative copper-tube / 9510 / alumina-ring coupons with the same
surface preparation, bond lengths, fill thickness, cure ramp, and cooling
fixture as the prototype. Inspect electrically and ultrasonically if possible,
then thermal-cycle in 10 °C increments with dwells. Do not assign a subzero
operating rating until the coupons establish a repeatable no-damage floor with
an appropriate margin.

## Primary sources

- MG Chemicals 9510 TDS, version 5.2, 23 January 2026:
  https://mgchemicals.com/downloads/tds/tds-9510.pdf
- CoorsTek Advanced Alumina property table:
  https://www2.coorstek.com/media/4235/advanced-alumina.pdf
- Copper Development Association C11000 properties:
  https://alloys.copper.org/alloy/C11000
- Vishay MMB 0207 datasheet (alumina ceramic body and operating range):
  https://www.vishay.com/docs/28963/mmu0102_mma0204_mmb0207.pdf

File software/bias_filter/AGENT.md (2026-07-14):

# Agent Guide: software/bias_filter

This directory contains project-owned geometry and simulation utilities for the Discoidal Capacitor Bias Filter.

Keep command-line tools deterministic and tied to the parameter names in `hardware/geometry/default-parameters.json`. Scripts should write generated outputs to `simulations/axisymmetric/outputs/` unless a caller requests another path.

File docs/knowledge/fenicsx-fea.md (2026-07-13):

# FEniCSx FEA Backend

## Recommendation

Use FEniCSx/DOLFINx as an optional backend, but keep the finite-difference worker available as the fast screening path until the FEniCSx peak-field convergence workflow is benchmarked.

FEniCSx is a good fit for the electrostatic solve because the problem is a scalar elliptic PDE with cylindrical symmetry:

```text
div(epsilon_r grad(V)) = 0
integral 2*pi*r*epsilon_r*grad(V).grad(w) dr dz = 0
```

The important caution is meshing. The maximum field depends on small rounded conductor edges and dielectric interfaces. A FEniCSx solve on a rectangle with conductor nodes merely sampled onto it would not be enough better than the current structured finite-difference screen. The current FEniCSx worker uses a conforming Gmsh/OpenCASCADE r-z dielectric domain with conductor regions removed as holes, so conductor surfaces and rounded edges are actual mesh boundaries. It still needs a peak-convergence loop before its supported or raw maximum should be treated as an acceptance value.

The remaining main simulation blocker is convergence, not package availability. The JavaScript/Python finite-difference solvers use the correct cylindrical r-z operator and give the expected `V / gap` field through the flat washer gap, but rounded-edge maxima remain sensitive to discretization. The FEniCSx path provides the conforming mesh needed for comparison; next it needs explicit local refinement and a stop rule based on peak-field and peak-location convergence.

## Current Implementation

`software/bias_filter/fenicsx_solver.py` implements the first conforming electrostatic FEA path:

- Gmsh/OpenCASCADE builds the r-z dielectric solve region between the conductive core radius and grounded tube inner radius.
- HV plates, ground plates, the conductive core boundary, and the grounded tube boundary are treated as equipotential conductor boundaries.
- The DOLFINx weak form uses the cylindrical weighting term, `r * epsilon_r * grad(V) . grad(w)`, so it is not a rectangular-coordinate Laplacian.
- `field_backend.py` runs FEniCSx solves in a separate Python subprocess. This avoids Gmsh signal-handler errors and keeps PETSc/MPI state outside the web server worker thread.
- Results are sampled back onto the same browser result contract used by the finite-difference backend, including material labels and dielectric-region peak fields.
- The material map is z-dependent: flat washer slabs occupy only the axial gaps between adjacent plate faces, while epoxy fills the rounded-edge pockets, core-side gap, tube-side gap, and other non-washer voids.
- Result payloads include a neighborhood-supported peak field, a raw point maximum, dielectric-region peaks, and peak-quality diagnostics.
- Result payloads also include capacitance checks. The ordinary field solve reports total two-terminal HV-to-ground capacitance from `C = 2U/V^2`. A separate local three-bias-plate solve estimates adjacent-bias parasitic capacitance.
- The exact `mirror_half` reference strategy meshes one physical end through the center of the middle plate. The center cut uses the weak form's natural zero-normal-flux boundary condition, energy is doubled, and sampled fields are mirrored back to the full-stack browser grid. `full_stack` remains available for regression comparisons.
- This is exact mirror symmetry for the idealized uniform finite stack. It is not a periodic-cell assumption; arbitrary interior cells retain small global end effects.

The first deployed same-geometry regression on 2026-07-13 used the 13.5 mm default stack and a 50 by 80 browser sampling grid. `mirror_half` meshed 6.75 mm and completed the full field-plus-three-capacitance-solve workflow in 2.433 s versus 5.167 s for `full_stack`, a 2.12x speedup. Total capacitance was 79.0094 pF versus 79.0101 pF, a relative difference of 0.00083%. The neighborhood-supported peak was 5.998 kV/mm versus 5.982 kV/mm, a relative difference of 0.267%. These satisfy the initial symmetry-regression tolerances; mesh convergence remains a separate requirement for breakdown acceptance.

The `Repeat interior FEA cell` checkbox is enabled by default and selects `end_repeat_approx`. It solves two axial regions: the physical end through the center of the first bias plate, and the first bias-plate center through the center of the second ground plate. The far end is the exact global mirror of the first region. The interior half-cell is copied and mirror-copied across alternating bias and ground center planes until the far-end region begins. The reconstructed ordinary field/capacitance result is marked approximate. Clear the checkbox to use exact `mirror_half` instead.

The three-bias `Cpar` polarization calculation cannot use the same repeated bias/ground cell because its bias-node voltages are deliberately different. It retains exact mirror symmetry through the driven middle bias plate. In approximation mode, its other boundary is moved to the center of the neighboring bias plate. The neighboring electrode keeps the voltage required by each of the three polarization solves, while the exposed radial annulus from the bias OD to the grounded tube is assigned 0 V. This removes the end washer and end ground region without incorrectly grounding a driven neighbor in the auxiliary solves.

The first six-pair Pi comparison used a 37.5 mm stack and a 50 by 120 browser sampling grid. `full_stack` took 14.079 s, exact `mirror_half` took 7.029 s, and `end_repeat_approx` took 4.049 s. The approximation therefore gave a 3.48x speedup over the full stack while solving 6.75 mm of combined unique axial extent. Its total capacitance was 236.369 pF versus 236.257 pF for the full stack, a 0.047% difference. Its neighborhood-supported peak was 5.966 kV/mm versus 6.009 kV/mm, a 0.728% difference. These results support the approximation as a fast screening option for the tested uniform geometry; they do not replace mesh convergence or full-stack checks for final acceptance.

On the default geometry, the exact mirror-half three-bias Cpar solve gave 0.128574 pF in 1.355 s over 9.75 mm of axial extent. The grounded-neighbor-cut approximation gave 0.128089 pF in 0.879 s over 6.0 mm, a 1.54x speedup and 0.378% difference.
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

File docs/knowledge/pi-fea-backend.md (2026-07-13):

# Pi FEA Backend Plan

## Design Goal

The web interface should keep quick design feedback in browser JavaScript while allowing the `Solve field` button to use a heavier Pi-hosted field solver when it is available.

## Multi-Client Rule

The Pi server can keep multiple clients straight if solves are treated as independent jobs. Do not make web requests write directly to shared `latest-*` output files, because two browser tabs or two people could overwrite each other's results.

Use a job ID as the authoritative handle:
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

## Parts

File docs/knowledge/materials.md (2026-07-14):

# Materials Notes

## Current Candidate Stack

Status: two candidate prototype cores sharing one mechanical stack; neither has yet been validated by high-voltage or low-frequency-noise testing.

- Washer dielectric: both prototype paths use stock alumina washers. Alumina is readily sourced, mechanically robust, and a conservative high-voltage ceramic choice, but its moderate relative permittivity limits the available shunt capacitance compared with high-k ceramics. That limitation is especially important for the lower-resistance MELF option at 50/60 Hz.
- Potting and fill: MG Chemicals 9510 One-Part Epoxy Potting Compound, Heat Cure. MG's SDS/TDS database lists 9510 as a one-part epoxy potting compound in liquid format. Pull the dielectric constant, dielectric strength, volume resistivity, cure schedule, shrinkage, and thermal limits from the current TDS before freezing model defaults.
- Resistive core / conductor path A: Fair-Rite type 61 NiZn ferrite is the first concrete bulk-resistive sample set. Its nominal resistivity is near the compact high-resistance target and it can be machined into discs, but excess 1/f noise from the polycrystalline conduction path is a primary measurement risk.
- Resistive core / conductor path B: high-value MELF resistors provide a specified, repeatable, low-noise component path. Readily available per-stage resistance is lower than preferred; combined with alumina's modest capacitance, the present simulated ladder gives poor attenuation at power-line frequency.
- Shared conductors: both prototypes use machined copper bias/ground plates and a copper ground tube because those parts are readily sourced and fabricated.
- Ferrite-to-plate contact: conductive epoxy between ferrite discs and bias plates. Exact product is TBD; verify contact resistance, cure compatibility, squeeze-out control, HV behavior, outgassing, and long-term stability.
- Mechanical positioning: temporary or permanent spacers to hold the plate, ferrite-disc, and washer stack aligned during conductive-epoxy cure and final potting.

## Assembly Process Candidate

- Cut the NiZn ferrite samples into discs with a diamond saw.
- Lap or polish the disc faces to controlled thickness and parallelism.
- Clean and inspect ferrite surfaces before bonding; record any chipped edges, cracks, or conductive debris.
- Assemble bias plates, ground plates, alumina washers, ferrite discs, spacers, and conductive-epoxy joints in the parameterized prototype fixture.
- Fill with MG Chemicals 9510 epoxy after the conductive joints and mechanical spacers hold the stack position.
- Vacuum degas aggressively, using repeated vacuum and nitrogen-pressure cycles if available, to reduce voids that could seed partial discharge.
- Cure using the vendor TDS schedule; record time, temperature, ramp rate, fixture constraint, and post-cure inspection.

## Resistive Core

The desired central resistance is approximately 100 Mohm to low Gohm. The first prototype may use NiZn ferrite if its volume resistivity gives the target resistance at reasonable dimensions.

The web model separates the core controls:

- `Core material`: preset selector for the material under consideration.
- `Use package diameter`: when the selected component has a known package OD,
  derive and lock Core OD to that value. Current package-derived values are
  1.4 mm for MELF 0204 and 2.2 mm for MELF 0207. Disable it for manual Core OD;
  materials without a known package diameter remain manual automatically.
- `Core volume resistivity`: log-scale input in ohm-cm. The app derives total core resistance from this value and the current core length and cross-sectional area.
- `Conductor epsr`: internal parameter name for effective relative permittivity, displayed in the UI as `Conductor &epsilon;<sub>r</sub>`.
- `Core R total`: derived readout kept for sizing and legacy parameter compatibility.

The `Conductor epsr` value is a rough circuit/parasitic modeling parameter, not a field-stress dielectric limit. For electrostatic field screening, the conductive core is an equipotential HV body; the solved dielectric immediately outside that core is epoxy/fill.

Current web presets:

| Preset | Circuit controls | Geometry/field placeholder | Use |
| --- | --- | --- | --- |
| Fair-Rite 61 NiZn | `epsr = 12`, `rho = 1e8 ohm-cm` | Conductive core OD from geometry | First physical ferrite sample set. |
| NiZn ferrite | `epsr = 15`, `rho = 1e8 ohm-cm` | Conductive core OD from geometry | Generic NiZn sensitivity check. |
| MMB0207 MELF | Defaults to direct `Stage R = 12 Mohm`; Cpar from effective ceramic/film geometry | 2.2 mm axial core surrogate | Single 0207 MELF modeled as a discrete direct stage by default. |
| MELF chain in 9510 | Defaults to direct `Stage R = 240 Mohm`, `Stage Cpar = 0.5 pF` | Conductive core OD from geometry | Epoxy-potted discrete resistor-chain approximation by default. |
| Conductive epoxy | `epsr = 4`, `rho = 1e-3 ohm-cm` | Conductive core OD from geometry | Placeholder for a conductive-epoxy-dominated core/contact region. |

Risks to investigate:

- Excess electrical noise.
- Voltage coefficient of resistance.
- Temperature dependence.
- Long-term stability.
- Surface leakage compared with bulk resistance.
- Compatibility with dielectric and mechanical assembly materials.
- Contact resistance and contact stability through the conductive-epoxy joints.
- Changes after cutting, polishing, cleaning, potting, and heat cure.

## Alternate Resistance Strategy

A chain of high-value MELF resistors may be preferable if ferrite performance is noisy, unstable, or difficult to control. This option may reduce uncertainty at the cost of more assembly complexity and possible parasitic structure.

A second MELF option is to use a single 0207 resistor as the per-stage axial element rather than a ferrite core segment. The package is just under 6 mm long by about 2.2 mm diameter, with approximately 3.2 mm between the metal end caps. A 1.5 mm thick plate and washer stack may therefore be mechanically plausible, and soldered end-cap joints could replace the ferrite-disc cutting, lapping, and conductive-epoxy bonding steps. In the web model, this is represented by the `MMB0207 MELF` preset with `core OD = 2.2 mm` for geometry/field visualization. Selecting the MELF preset checks `Direct stage RC inputs` by default, exposing direct per-stage resistance while modeling Cpar from the ceramic body and surrounding epoxy.

The main benefit is a specified low-noise resistor technology instead of a ferrite body whose bias-noise behavior is uncertain. The main risk is stray capacitance from the spiral-trimmed metal-film structure and end-cap geometry. The current first-draft model uses `eps_eff = eps_substrate / (1 - film_fill_factor)`, defaulting to alumina-like `eps_substrate = 9.8` and `film_fill_factor = 0.50` for 0207. This needs either a geometry-specific measurement or a better package model before final design.

Current MELF-chain candidate: Vishay Beyschlag MMB 0207 professional thin-film MELF, now using 12 Mohm as the default per-stage value because that value was found in stock. Verify the exact orderable code before purchase.

Important correction: do not size this resistor option as if the full 6 kV DC detector bias appears across the MELF resistor in normal operation. The detector load is below 1 nA, so the steady resistor drop is approximately `I * R`, not the full supply voltage. Use `docs/knowledge/resistor-voltage-stress.md` before making resistor voltage-rating or resistor-count arguments. Pulse/surge robustness may still matter if a dielectric breakdown dumps stored capacitance, but that is a pF-scale capacitive-energy question rather than a steady 6 kV-per-string requirement.

The MELF option should still be modeled as a physical resistor body or routed resistor chain, not as a perfectly uniform conductive cylinder, once the intended routing is known. Main risks are local field enhancement at resistor terminations and joints, parasitic capacitance to ground and across the stage, surface leakage after potting, pulse/surge response, and long-term compatibility with heat-cured epoxy.

## Dielectric Selection

The design likely benefits from more than one dielectric:

- High permittivity in the HV-to-ground overlap region for capacitance.
- Low permittivity near the resistive core to reduce parasitic capacitance.
- Possibly low permittivity outside the plate overlap to manage fringe fields.

Candidate materials should be tracked with permittivity, dielectric strength, loss tangent, volume resistivity, machinability, outgassing, radiopurity if relevant, and availability.

In code and JSON, the suffix `epsr` means relative permittivity, `epsilon_r`. The web UI should display this as `&epsilon;<sub>r</sub>` where possible.

## Washer Dielectric Options

Approximate capacitance improvement in the web model scales linearly with washer `epsr`, because the first-pass estimate is a parallel-plate capacitance through the washer overlap region. The app now defaults to alumina (`epsr = 10`) and reports `C vs FR4` using FR4/G10 as `epsr = 4.4`.

The web interface uses provisional dielectric-strength values to set minimum clearances. It rounds the minimum upward from `bias_voltage / dielectric_strength`. The core-to-ground radial gap uses the epoxy/fill breakdown value for that minimum because epoxy occupies that region; its maximum comes from the available geometry while preserving the minimum radial overlap between the ground and HV plates, with the backend's 50 mm limit as the final ceiling. Washer-controlled axial ranges retain the 10-times-minimum screening range. Custom and generic high-K screening presets use a `0.4 mm` fallback minimum until a real material is selected. After a field solve, the web interface reports the neighborhood-supported electric field in the washer and epoxy/fill regions and displays `E_breakdown / E_max` as a first-pass design margin where a placeholder breakdown strength is available. The raw point maximum remains available as a mesh-artifact diagnostic. The epoxy/fill bucket includes the core-to-ground dielectric gap around the conductive core and the rounded-edge pockets outside the flat washer slabs.

These values are not qualification limits. Actual breakdown depends on thickness, electrode geometry, surface finish, humidity, voids, interfaces, defects, and test protocol.

| Candidate | Web epsr placeholder | Web dielectric-strength placeholder | Capacitance vs FR4 | Practical read |
| --- | ---: | ---: | ---: | --- |
| FR4/G10 | 4.4 | 20 kV/mm | 1.0x | Practical fallback if alumina washers are unavailable. Easy to mill, drill, and iterate. Check HV leakage after machining and cleaning. |
| Macor or similar machinable glass ceramic | 6 | 40 kV/mm | 1.4x | More ceramic-like and machinable with ordinary shop tooling, but not a high-permittivity win. Useful if FR4 outgassing or moisture is a concern. |
| Alumina | 10 | 13 kV/mm | 2.3x | Preferred washer target. Good electrical/mechanical baseline, non-piezoelectric, and likely lower PD risk than polymer washers when dense, clean, uncracked, and well bonded. Prefer purchased washers or vendor grinding/laser/waterjet service. |
| Zirconia or ZTA | 25 | 10 kV/mm | 5.7x | Potentially higher permittivity than alumina and mechanically tough, but verify dielectric strength, loss, resistivity, and availability in washer geometry. |
| BaTiO3 / PZT class electroceramic | 100 placeholder | custom range | 22.7x placeholder | Screening-only / likely no-go. Electrically attractive, but ferroelectric or piezoelectric behavior can create microphonics, voltage coefficient, dielectric loss, and temperature sensitivity. |
| SrTiO3 or other non-piezo high-K ceramic | 100 placeholder | custom range | 22.7x placeholder | Screening-only. Avoid unless an actual washer or coupon has low loss, low leakage, low voltage coefficient, and no measurable microphonic response. |

Sourcing strategy:

- For the first build, search for stock alumina insulating washers first; if the dimensions are not available, ask a technical ceramics shop for laser-cut, waterjet-cut, diamond-ground, or fired-to-shape alumina washers.
- If alumina sourcing stalls, cut FR4/G10 washers from laminate sheet or buy Garolite/FR4 insulating washers if the dimensions are close enough.
- For a higher-permittivity structural ceramic, ask custom ceramics vendors about zirconia or ZTA washers and request dielectric-property data at the relevant field, frequency, and temperature.
- Avoid piezoelectric high-K rings for the main dielectric path unless a coupon test proves microphonics are negligible. If high-K is revisited, prefer non-piezo candidates and treat all of them as test coupons rather than final dielectric washers.
- Test at least one washer coupon by measuring capacitance, leakage versus voltage, dissipation factor if possible, and microphonic response before embedding it in potted hardware.

### Alumina purity and detector-bias partial discharge

Commercial 96% alumina is a dense ceramic with sintering aids and secondary
phases; the remaining percentage is not a porosity percentage. Representative
Vishay substrate data give 96% alumina `epsr = 9.6`, loss tangent `0.0002`, and
dielectric strength `19 kV/mm`, compared with `epsr = 9.8--9.9`, loss tangent
`0.0001`, and dielectric strength `23 kV/mm` for 99.5--99.6% grades. These are
grade- and test-specific examples, not universal acceptance values:

https://www.vishay.com/docs/48666/_ms12821832-2306_design-guidelines_ultrasource_reduced-file-size.pdf

For DC detector bias, a small partial discharge matters even when it cannot
bridge the insulation: its current pulse can couple into the detector signal.
Likely initiation sites are gas voids, cracks, surface contamination, and
epoxy/ceramic delamination. A gas void can carry a much higher local field than
the surrounding solid because of the permittivity discontinuity. Wall charge
may temporarily extinguish a DC discharge, but leakage, relaxation, ripple, or
ionization can permit intermittent recurrence.

Treat purity as secondary to explicit density/open-porosity, water-absorption,
surface-finish, edge-quality, and dielectric-test specifications. Higher-purity
substrates are often available with finer surfaces, but a well-finished 96%
washer with complete epoxy wetting is preferable to a nominally purer part
that traps air or develops a weak interface. Coupon qualification should
include cleaning and drying, representative vacuum-assisted potting, the real
cure schedule, thermal cycling, and a sensitive DC partial-discharge or
current-pulse test.

## Epoxy Fill Options

The epoxy fill is selectable in the web model. MG Chemicals 9510 remains the
mechanical-analysis baseline, while flexible candidates are included for
electrical and process comparison.

Current web presets:

| Preset | Web epsr | Dielectric strength | Use |
| --- | ---: | ---: | --- |
| MG Chemicals 9510 | 3.7 | 15.75 kV/mm | One-part, heat-cured mechanical baseline. |
| MG Chemicals 832FX | 3.1 | 12.99 kV/mm | Low-viscosity flexible epoxy with two-hour working time. |
| MG Chemicals 832FXT | 3.1, provisional | 13.78 kV/mm | Flexible small-package prototype candidate. |
| MG Chemicals 832FXC | 3.1, provisional | 18.58 kV/mm | Clear, very low-viscosity option for void inspection. |
| Epoxies Etc. 20-3241 | 4.7 | 22.05 kV/mm | Low-stress candidate with strong published electrical data but short pot life. |
| Generic potting epoxy | 3.2 | 15 kV/mm | Sensitivity placeholder for ordinary epoxy potting compounds. |
| Low-k epoxy | 2.8 | 15 kV/mm | Sensitivity placeholder for lower-permittivity fill choices. |
| Custom | user-set | unset | Manual value for datasheet or measured candidates. |

See `docs/knowledge/epoxy-selection.md` for the complete process/property
comparison, source links, silicone alternatives, and qualification plan. The
832FXT and 832FXC permittivities are explicit estimates from the related 832FX,
not published values.

## Thermal mismatch warning

The heat-cured default 9510/alumina/copper assembly has a potentially limiting
cold-temperature bond risk even though the cured epoxy itself is specified to
-65 °C. The conservative fully restrained screen predicts a nominal strength
crossing near +4 °C; the assumed 2 to 4 GPa modulus range moves the crossing
from approximately -29 to +21 °C, while a 50% restraint sensitivity moves it
to approximately -62 °C. This wide range is caused by
unpublished 9510 modulus/interface-fracture data and uncertain free-edge relief.

Treat `docs/knowledge/thermal-stress.md` and
`simulations/thermal/outputs/default-thermal-stress.json` as the calculation of
record. Do not assign a subzero assembly rating until representative bonded-ring
coupons survive staged thermal cycling. Until then, transport the assembly at
controlled room temperature, preferably at or above 25 °C, and avoid unheated
or freezing shipment.

The 3.9% shrinkage number currently carried by the thermal calculation comes
from the MG Chemicals 9510 TDS, version 5.2 (23 January 2026), page 2. In the
Liquid Properties table the complete entry is `Shrinkage 3.9% Calculated`.
The TDS does not say whether it is linear, volumetric, mass-based, or tied to a
specific cure/gel reference state. It also reports a separate 3.9% weight loss
at 155 °C after 600 hours on page 3; do not confuse that unrelated property
with shrinkage. Resolving the definition and the post-gel locked-in fraction is
a priority follow-up before residual cure stress is added to the model.

## Alumina And Partial Discharge Notes

Alumina is not automatically void-free, but dense technical alumina is a strong candidate for low partial-discharge risk because it is a hard, inorganic, non-piezoelectric electrical insulator with stable permittivity near the target range. The likely PD initiators in this assembly are not bulk alumina pores first; they are gas voids, cracks, chipped washer edges, rough or contaminated surfaces, trapped bubbles in potting epoxy, and conductor/dielectric interface gaps.

Working interpretation:

- Dense purchased alumina washers are preferred over hand-machined ceramic when possible.
- Surface finish, edge chips, washer flatness, and trapped interface bubbles may dominate over nominal bulk material choice.
- Vacuum/pressure cycling of the potting epoxy is still important because voids in epoxy or at interfaces can seed partial discharge even if the washer body is dense.
- Visual inspection under magnification and a stepped HV/PD/leakage test should be part of washer qualification.

## Material and Process Risks

- Conductive epoxy squeeze-out could create local field enhancement, leakage paths, or bias-to-ground shorts.
- Voids in the potting compound could seed partial discharge, especially near conductor edges and ferrite/epoxy interfaces.
- Ferrite cutting and polishing may change surface leakage enough that bulk-resistivity estimates are misleading.
- Epoxy shrinkage and cure stress could crack ferrite or alumina, open conductive joints, or warp the plate stack.
- Coefficient-of-thermal-expansion mismatch between alumina, ferrite, metal plates, conductive epoxy, and potting epoxy needs a temperature-cycle check.
- Alumina washer edge chipping or sharp metal burrs could dominate the local field even if the nominal geometry is rounded.
- FR4/G10 can absorb moisture and may leave rough glass fibers or resin smear after machining; clean and bake test coupons before HV tests.
- High-permittivity electroceramics can have large voltage and temperature coefficients, dielectric loss, and piezoelectric/microphonic response; treat piezoelectric candidates as likely no-go for the main washer dielectric.

## Source Links

- MG Chemicals SDS/TDS database: https://mgchemicals.com/sds-tds/
- MG Chemicals potting-compounds overview: https://mgchemicals.com/category/potting-compounds/
- Fair-Rite materials table: https://fair-rite.com/materials/
- FR-4 overview and typical relative permittivity: https://en.wikipedia.org/wiki/FR-4
- Dielectric-strength caveats and material overview: https://en.wikipedia.org/wiki/Dielectric_strength
- Macor machinable glass-ceramic overview: https://en.wikipedia.org/wiki/Macor
- Barium titanate high-permittivity electroceramic overview: https://en.wikipedia.org/wiki/Barium_titanate
- Lead zirconate titanate electroceramic overview: https://en.wikipedia.org/wiki/Lead_zirconate_titanate
- Strontium titanate dielectric overview: https://en.wikipedia.org/wiki/Strontium_titanate
- Partial discharge overview: https://en.wikipedia.org/wiki/Partial_discharge
- Alumina / aluminium oxide overview: https://en.wikipedia.org/wiki/Aluminium_oxide
- Vishay Beyschlag MMB 0207 professional MELF resistor datasheet: https://www.vishay.com/docs/28713/melfprof.pdf

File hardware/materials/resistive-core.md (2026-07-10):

# Resistive Core Candidates

## Web Model Presets

The browser interface uses a generic `Core material` selector plus independent `Enter stage R` and `Enter resistor Cpar` checkboxes. Resistance can therefore be entered per stage or derived from core resistivity and geometry with `R = rho L / A`, independently of whether capacitance is entered or calculated. Entered resistor/package Cpar is combined with the separately calculated epoxy coupling. Calculated Cpar uses the selected core material and geometry plus epoxy around the core. These placeholders do not replace measured resistance, leakage, or noise data.

Current placeholders:

- Fair-Rite 61 NiZn: `epsr = 12`, `rho = 1e8 ohm-cm`.
- Generic NiZn ferrite: `epsr = 15`, `rho = 1e8 ohm-cm`.
- Vishay MMB0207 12 Mohm MELF: defaults to entered stage resistance with `Stage R = 12 Mohm`, `core OD = 2.2 mm`, and calculated geometric/effective-medium Cpar.
- MELF chain in MG 9510 epoxy: defaults to entered stage resistance and entered package capacitance with `Stage R = 240 Mohm`, `Stage Cpar = 0.5 pF`.
- Conductive-epoxy-dominated core/contact region: `epsr = 4`, `rho = 1e-3 ohm-cm`.
- Custom: user-set `Conductor epsr` and volume resistivity.

## NiZn Ferrite

Possible first-prototype material because its volume resistivity may produce a total resistance near 100 Mohm in a compact cylindrical geometry.

### Fair-Rite Type 61 Candidate

Fair-Rite type 61 is the current first material to test. Fair-Rite lists it as a NiZn ferrite with initial permeability 125, Curie temperature greater than 300 C, and resistivity around 1e8 ohm-cm. At that nominal resistivity, millimeter-thick discs in the 4 mm to 6 mm diameter range land in an interesting resistance range for the central bias path, but the real value must be measured on the actual cut and polished samples.

Available first-test sample diameters:

- 4 mm.
- 5 mm.
- 6 mm.

Planned material preparation:

- Cut discs with a diamond saw.
- Polish or lap both faces to target thickness and parallelism.
- Inspect for chips, cracks, smeared conductive debris, and edge damage.
- Clean before resistance and contact tests.

Measurements to run before committing to this core strategy:

- Resistance versus disc thickness and area.
- Leakage current versus voltage and polarity.
- Noise under representative high-voltage low-current bias.
- Temperature coefficient and drift after thermal cycling.
- Surface leakage compared with bulk resistance.
- Contact resistance with the chosen conductive epoxy.
- Resistance and leakage before and after final epoxy potting and heat cure.

Unknowns:

- Noise under high-voltage low-current bias.
- Resistance uniformity and tolerance.
- Voltage and temperature coefficients.
- Surface leakage behavior.
- Compatibility with the dielectric stack and assembly process.
- Conductive-epoxy contact stability.
- Behavior after cutting, polishing, cleaning, potting, and heat cure.

## MELF Resistor Chain

Likely fallback if ferrite is noisy or insufficiently predictable.

### Vishay MMB 0207 As Per-Stage Core

Current concrete alternate: a 0207 MELF resistor in the 10 Mohm to 15 Mohm range, with the web default now set to the 12 Mohm value that was found in stock. The body is just under 6 mm long and about 2.2 mm diameter, with roughly 3.2 mm between metal end caps. That geometry looks compatible with a 1.5 mm thick plate plus washer stack if the resistor is soldered into the bias path instead of bonding ferrite discs with conductive epoxy.

For the current axisymmetric field-screening model, approximate this option as a `2.2 mm` diameter central core for geometry and local electric-field visualization. For the RC ladder model, the preset checks `Enter stage R` and leaves `Enter resistor Cpar` unchecked, so one 12 Mohm 0207 MELF is used per stage while capacitance remains geometric. The MELF body is treated as an alumina ceramic substrate with an effective-permittivity correction for metal-film shielding,

```text
eps_eff = eps_substrate / (1 - film_fill_factor)
```

The current 0207 default is `eps_substrate = 9.8` and `film_fill_factor = 0.50`, so `eps_eff = 19.6`. This is an educated first-draft approximation for a high-value spiral-trimmed film resistor, not a substitute for direct impedance/parasitic measurement.

Advantages compared with ferrite discs:

- No need to cut ferrite discs.
- No need to epoxy ferrite to the bias discs; soldered terminations become possible.
- Thin-film MELF parts are specified, repeatable, and expected to be low noise, while ferrite noise remains suspect.

Possible issue:

- The spiral-trimmed metal film may create significant stray capacitance if it occupies much of the resistor body. The current model treats this as an effective-permittivity multiplier rather than trying to resolve the proprietary film path.

### Vishay MMB 0207 Candidate

Current candidate under consideration: Vishay Beyschlag professional thin-film MELF 0207 in the high-Mohm MMB 0207 family. Verify the exact orderable code before purchase, especially for the 12 Mohm stocked value now used by the web default.

Useful official limits from the 2026-01-20 Vishay MMB 0207 professional datasheet:

- Resistance range reaches 15 Mohm for MMB 0207, so 10 Mohm and possibly 15 Mohm values are in-family.
- 10 Mohm falls in the 50 ppm/K, 1% range; the tighter 25 ppm/K, 0.5% range only reaches 1 Mohm for MMB 0207.
- Rated operating voltage is 350 V AC RMS/DC per resistor.
- Rated dissipation is 1 W in power operation and 0.4 W in the standard low-drift operating mode, subject to film temperature.
- Body size is about 5.8 mm long by 2.2 mm diameter.

First-pass sizing correction:

- The `MMB0207 MELF` web preset is one 12 Mohm part per direct stage, with Cpar estimated from the effective ceramic/film body plus surrounding epoxy geometry.
- A 24-part / 240 Mohm chain remains a possible resistance scenario, but it is not the default single-MELF stage.
- Do not size the resistor count as if the full 6 kV detector-bias supply appears across the resistor string in normal operation. With sub-nA detector current, steady resistor drop is `I * R`.
- See `docs/knowledge/resistor-voltage-stress.md` before making resistor voltage-rating or resistor-count arguments.
- Pulse/surge robustness still matters for dielectric-breakdown faults, but the energy is set by the capacitance that discharges, usually pF-scale, not by a continuous full-bias resistor drop.
- The mechanical length of a simple end-to-end chain may still be noncompact; any chain build needs a routed geometry and a fresh parasitic-capacitance estimate.

Main design risks for the MELF-chain version:

- Local electric-field enhancement at resistor end caps, solder/conductive-epoxy joints, and any folded-chain turns.
- Distributed parasitic capacitance from the resistor string to ground and between bias nodes.
- Pulse/surge behavior for small capacitive discharge events.
- Potting-compound compatibility and long-term stability after heat cure.
- Surface leakage along resistor bodies, terminations, board/substrate surfaces, or epoxy interfaces.
- Assembly repeatability if the chain must fit inside the current washer/tube envelope.

Advantages:

- Better-specified resistance.
- Easier sourcing and repeatability.
- Clearer electrical model.

Concerns:

- More assembly complexity.
- Local field enhancement around discrete components.
- Parasitic capacitance along the resistor chain.

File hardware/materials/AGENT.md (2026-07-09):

# Agent Guide: hardware/materials

Use this directory for material candidates, measured properties, datasheet extracts, and decision records.

For each material, track source, property values, uncertainty, operating voltage relevance, and whether the value is measured, simulated, specified, or assumed.

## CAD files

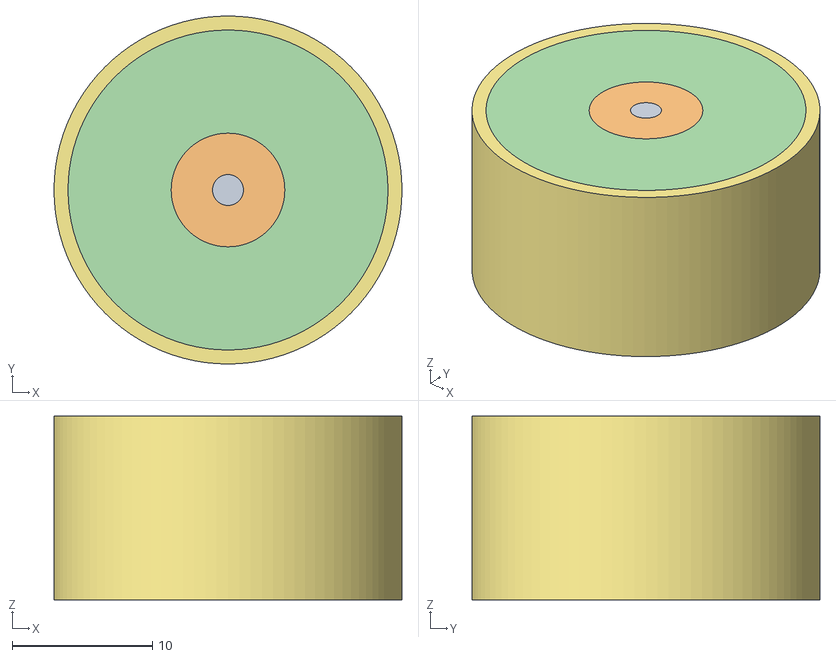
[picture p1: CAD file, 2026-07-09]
hardware/geometry/generated/latest-model.obj
24.8 x 24.8 x 13.1
core_region
epoxy_fill_envelope
washer_dielectric_region_00
washer_dielectric_region_01
washer_dielectric_region_02
washer_dielectric_region_03
ground_tube
ground_plate_00
hv_plate_01
ground_plate_02
hv_plate_03
ground_plate_04

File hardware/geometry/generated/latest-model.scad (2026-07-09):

// Generated from hardware/geometry/default-parameters.json
// Units: millimeters. Axis of revolution is OpenSCAD Z.
$fn = 128;

module rz_body(points) {
  rotate_extrude(convexity = 10) polygon(points = points);
}

// core_region
color([0.54, 0.36, 0.19, 0.55]) rz_body([[0, 0], [1.1, 0], [1.1, 13.1], [0, 13.1]]);

// epoxy_fill_envelope
color([0.73, 0.86, 0.84, 0.22]) rz_body([[1.1, 0], [11.4, 0], [11.4, 13.1], [1.1, 13.1]]);

// washer_dielectric_region_00
color([0.84, 0.72, 0.36, 0.35]) rz_body([[3.3, 1.5], [9.4, 1.5], [9.4, 2.9], [3.3, 2.9]]);

// washer_dielectric_region_01
color([0.84, 0.72, 0.36, 0.35]) rz_body([[3.3, 4.4], [9.4, 4.4], [9.4, 5.8], [3.3, 5.8]]);

// washer_dielectric_region_02
color([0.84, 0.72, 0.36, 0.35]) rz_body([[3.3, 7.3], [9.4, 7.3], [9.4, 8.7], [3.3, 8.7]]);

// washer_dielectric_region_03
color([0.84, 0.72, 0.36, 0.35]) rz_body([[3.3, 10.2], [9.4, 10.2], [9.4, 11.6], [3.3, 11.6]]);

// ground_tube
color([0.33, 0.48, 0.22, 1]) rz_body([[11.4, 0], [12.4, 0], [12.4, 13.1], [11.4, 13.1]]);

// ground_plate_00
color([0.33, 0.48, 0.22, 1]) rz_body([[4.05, 0], [11.4, 0], [11.4, 1.5], [4.05, 1.5], [3.90368, 1.48559], [3.76299, 1.44291], [3.63332, 1.3736], [3.51967, 1.28033], [3.4264, 1.16668], [3.35709, 1.03701], [3.31441, 0.896318], [3.3, 0.75], [3.3, 0.75], [3.31441, 0.603682], [3.35709, 0.462987], [3.4264, 0.333322], [3.51967, 0.21967], [3.63332, 0.126398], [3.76299, 0.0570904], [3.90368, 0.014411], [4.05, 0]]);

// hv_plate_01
color([0.72, 0.24, 0.24, 1]) rz_body([[1.1, 2.9], [8.65, 2.9], [8.79632, 2.91441], [8.93701, 2.95709], [9.06668, 3.0264], [9.18033, 3.11967], [9.2736, 3.23332], [9.34291, 3.36299], [9.38559, 3.50368], [9.4, 3.65], [9.4, 3.65], [9.38559, 3.79632], [9.34291, 3.93701], [9.2736, 4.06668], [9.18033, 4.18033], [9.06668, 4.2736], [8.93701, 4.34291], [8.79632, 4.38559], [8.65, 4.4], [1.1, 4.4]]);

// ground_plate_02
color([0.33, 0.48, 0.22, 1]) rz_body([[4.05, 5.8], [11.4, 5.8], [11.4, 7.3], [4.05, 7.3], [3.90368, 7.28559], [3.76299, 7.24291], [3.63332, 7.1736], [3.51967, 7.08033], [3.4264, 6.96668], [3.35709, 6.83701], [3.31441, 6.69632], [3.3, 6.55], [3.3, 6.55], [3.31441, 6.40368], [3.35709, 6.26299], [3.4264, 6.13332], [3.51967, 6.01967], [3.63332, 5.9264], [3.76299, 5.85709], [3.90368, 5.81441], [4.05, 5.8]]);

// hv_plate_03
color([0.72, 0.24, 0.24, 1]) rz_body([[1.1, 8.7], [8.65, 8.7], [8.79632, 8.71441], [8.93701, 8.75709], [9.06668, 8.8264], [9.18033, 8.91967], [9.2736, 9.03332], [9.34291, 9.16299], [9.38559, 9.30368], [9.4, 9.45], [9.4, 9.45], [9.38559, 9.59632], [9.34291, 9.73701], [9.2736, 9.86668], [9.18033, 9.98033], [9.06668, 10.0736], [8.93701, 10.1429], [8.79632, 10.1856], [8.65, 10.2], [1.1, 10.2]]);

// ground_plate_04
color([0.33, 0.48, 0.22, 1]) rz_body([[4.05, 11.6], [11.4, 11.6], [11.4, 13.1], [4.05, 13.1], [3.90368, 13.0856], [3.76299, 13.0429], [3.63332, 12.9736], [3.51967, 12.8803], [3.4264, 12.7667], [3.35709, 12.637], [3.31441, 12.4963], [3.3, 12.35], [3.3, 12.35], [3.31441, 12.2037], [3.35709, 12.063], [3.4264, 11.9333], [3.51967, 11.8197], [3.63332, 11.7264], [3.76299, 11.6571], [3.90368, 11.6144], [4.05, 11.6]]);

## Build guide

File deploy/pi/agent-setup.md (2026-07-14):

# Agent Setup For Raspberry Pi Hosting

This file is for the AI agent, not a human copy-and-paste tutorial. Own the setup from the user's current starting point through a verified hosted page. Explain physical and Raspberry Pi Imager steps at the level of detail the user requests, discover values when possible, and give the user fully rendered commands when a manual action is unavoidable.

Never ask a human to replace placeholders such as `PASTE_PUBLIC_KEY_HERE`. Generate a dedicated key, read its public half, and insert the actual public key, username, and paths into the exact command you ask the user to run.

## Target Architecture

- The coding agent runs on the user's Windows, macOS, or Linux computer.
- A dedicated Raspberry Pi runs Raspberry Pi OS 64-bit and hosts the web app, FEniCSx backend, and SPICE backend.
- The agent connects to the Pi over SSH using a dedicated key and a dedicated `agent` account.
- The `agent` account has blanket passwordless sudo because this workflow is intended for an AI-controlled development Pi.

The recommended model treats the Pi as an expendable AI development device. Once the user selects this model, install `agent ALL=(ALL) NOPASSWD: ALL` and do not repeatedly ask for authorization before package installation, service changes, reboots, or other ordinary administrative work needed to develop and verify the project. Important source and results must remain in Git or other off-device storage. If the OS becomes badly damaged, reimaging the microSD card is the clean recovery path.

Confirm the trust model only when it has not already been established. If the Pi is shared, contains sensitive data, or serves unrelated production work, use a narrower privilege model instead.

## Phase 1: Establish The Pi

First determine what the user already has. Do not repeat completed steps. The normal hardware target is a Raspberry Pi 5 with 4 GB RAM, a 64 GB high-endurance microSD card, the correct power supply, and Ethernet or Wi-Fi on the same reachable network as the agent's computer. A 2 GB Pi is the practical minimum for the current single-worker service; measured default electric and thermal FEniCSx subprocesses peaked at about 157 MiB and 252 MiB RSS, with peak total system use below 0.8 GiB. A Pi 4 with 2 GB or more is a slower fallback. Prefer 8 GB only when the user expects unusually fine meshes, other substantial services, or broader development work on the same Pi.

If the OS is not installed, walk the user through the current Raspberry Pi Imager interface:

1. Install Raspberry Pi OS 64-bit.
2. Set a recognizable hostname.
3. Create a human administrator account whose password remains known only to the user.
4. Configure Wi-Fi if Ethernet will not be used.
5. Enable SSH.
6. Recommend Raspberry Pi Connect as a recovery path during initial setup.
7. Boot the Pi and help the user find or verify its hostname or IP address.

The human administrator account is only for bootstrap and recovery. Do not request or record its password. Ask the user to run privileged bootstrap commands in a terminal on the Pi or in their own SSH session when needed.

## Phase 2: Create Dedicated Agent Access

On the agent's local computer, choose a dedicated key path appropriate to the OS. Reuse an existing project-specific key only if its private file is present and protected. Otherwise generate an Ed25519 key non-interactively, with no passphrase so the agent can reconnect unattended. Do not overwrite an existing key.

Example key names:

- Linux/macOS: `~/.ssh/discoidal_capacitor_bias_filter_agent_ed25519`
- Windows: `%USERPROFILE%\.ssh\discoidal_capacitor_bias_filter_agent_ed25519`

Read the generated `.pub` file. Then render one complete bootstrap command for the user to paste into a terminal logged into the Pi as their human administrator. The rendered command must:

1. Create the `agent` account if it does not exist.
2. Create `/home/agent/.ssh` with mode `700` and correct ownership.
3. Write the actual public key to `/home/agent/.ssh/authorized_keys` with mode `600`.
4. Write a temporary sudoers rule containing `agent ALL=(ALL) NOPASSWD: ALL`.
5. Validate the temporary file with `visudo -cf`, then install it as `/etc/sudoers.d/discoidal-capacitor-bias-filter-agent` with mode `440`.

Use careful shell quoting around the actual public key. Build the command internally from a fixed account name and the public key you just generated; do not interpolate untrusted text from the user. The command shown to the human must contain no unresolved variables or placeholder tokens. It is acceptable for their existing administrator account to prompt for its sudo password; never ask them to share it with the agent.

After the user runs the command, test SSH from the agent's computer using the dedicated private key. Verify at least:

```bash
whoami
hostname
sudo -n true
```

Do not continue until the connection identifies the dedicated account and non-interactive sudo succeeds. Store host-specific connection details only in an ignored local file such as `.secrets/current-deployment.md`. Never commit the private key, passwords, IP address, or current deployment paths.

## Phase 3: Install And Deploy

Once SSH works, carry out the remaining steps directly over SSH. Ask the user to paste further commands only when the agent's environment cannot perform the operation itself.

Before changing the machine, record the current OS and architecture with `cat /etc/os-release` and `uname -m`. The intended platform is a current 64-bit Raspberry Pi OS or Debian-family installation reporting `aarch64`. If the Pi is 32-bit, stop and recommend reimaging it with a 64-bit OS rather than attempting a partial FEniCSx installation.

## Inputs To Collect

Before running commands, identify:

- `PI_ADDRESS`: hostname or IP address used from the user's workstation.
- `SSH_KEY_PATH`: local path to the dedicated private key.
- `AGENT_USER`: normally `agent`.
- `REPOSITORY_URL`: Git URL for this repository, if cloning from Git.
- `PROJECT_DIR`: repository checkout or synced working tree on the Pi.
- `STATIC_ROOT`: document root served by the backend.
- `APP_PATH`: URL path for the app, usually `/discoidal-capacitor-bias-filter/`.
- `STATIC_DIR`: static app directory, usually `STATIC_ROOT` plus `APP_PATH`.
- `SERVICE_NAME`: systemd service name.

If there is no Git remote available, sync the repository contents by the mechanism available in the current environment, then continue from the same `PROJECT_DIR`.

Use shell variables for the rest of setup so the commands can be adapted to the user's Pi:

```bash
export AGENT_USER="${AGENT_USER:-$(whoami)}"
export REPOSITORY_URL="${REPOSITORY_URL:-https://github.com/EricLarueMartin/DiscoidalCapacitorBiasFilter.git}"
export PROJECT_DIR="${PROJECT_DIR:-$HOME/projects/DiscoidalCapacitorBiasFilter}"
export STATIC_ROOT="${STATIC_ROOT:-$HOME/sites/public}"
export APP_PATH="${APP_PATH:-/discoidal-capacitor-bias-filter/}"
export STATIC_DIR="${STATIC_DIR:-${STATIC_ROOT%/}${APP_PATH}}"
export SERVICE_NAME="${SERVICE_NAME:-agent-sites.service}"
```

## 1. Install Packages

Read and follow [package-requirements.md](package-requirements.md). Install the base packages, FEniCSx/Gmsh packages, and `ngspice` if available.

After package installation, verify:

```bash
python3 - <<'PY'
import dolfinx, gmsh, mpi4py, petsc4py, ufl
print("FEniCSx import check passed")
PY
```

```bash
ngspice -v || true
```

## 2. Clone Or Sync The Repository

Create the project parent:

```bash
sudo install -d -m 755 -o "$AGENT_USER" -g "$AGENT_USER" "$(dirname "$PROJECT_DIR")"
```

If `PROJECT_DIR` does not exist and a Git URL is available:

```bash
git clone "$REPOSITORY_URL" "$PROJECT_DIR"
```

If `PROJECT_DIR` already exists:

```bash
cd "$PROJECT_DIR"
git pull --ff-only || true
```

If Git is not available for this repository, copy or rsync the local working tree into `PROJECT_DIR`. Preserve file paths.

## 3. Install Static Web Files

```bash
sudo install -d -m 755 -o "$AGENT_USER" -g "$AGENT_USER" "$STATIC_DIR"
rsync -a --delete "$PROJECT_DIR/presentations/web/" "$STATIC_DIR/"
```

Create a landing page that redirects to the project:

```bash
cat > /tmp/discoidal-filter-index.html <<HTML
<!doctype html>
<html>
  <head>
    <meta charset="utf-8">
    <meta http-equiv="refresh" content="0; url=$APP_PATH">
    <title>Discoidal Capacitor Bias Filter</title>
  </head>
  <body>
    <p><a href="$APP_PATH">Discoidal Capacitor Bias Filter</a></p>
  </body>
</html>
HTML
sudo install -d -m 755 -o "$AGENT_USER" -g "$AGENT_USER" "$STATIC_ROOT"
sudo install -m 644 -o "$AGENT_USER" -g "$AGENT_USER" /tmp/discoidal-filter-index.html "$STATIC_ROOT/index.html"
```

## 4. Install The systemd Service

```bash
cd "$PROJECT_DIR"
sed \
  -e "s#__AGENT_USER__#$AGENT_USER#g" \
  -e "s#__PROJECT_DIR__#$PROJECT_DIR#g" \
  -e "s#__STATIC_ROOT__#$STATIC_ROOT#g" \
  deploy/pi/agent-sites.service > "/tmp/$SERVICE_NAME"
sudo install -m 644 "/tmp/$SERVICE_NAME" "/etc/systemd/system/$SERVICE_NAME"
sudo systemctl daemon-reload
sudo systemctl enable --now "$SERVICE_NAME"
systemctl status "$SERVICE_NAME" --no-pager -l
```

The service defaults to `--solver fd` for fast screening. Browser requests can still choose `FEniCSx required`; the request payload selects the FEniCSx worker per job.

## 5. Smoke Test The Service

Local Pi checks:

```bash
curl -fsS http://127.0.0.1/api/health
curl -fsS "http://127.0.0.1$APP_PATH" | grep -i "Discoidal Capacitor Bias Filter"
```

Finite-difference job and automatic polling:

```bash
python3 - <<'PY'
import json
import time
import urllib.request

base = "http://127.0.0.1"
payload = {
    "client_id": "setup-smoke",
    "solver": "fd",
    "parameters": {
        "plate_pairs": 1,
        "grid_r_count": 24,
        "grid_z_count": 36,
        "solver_iterations": 80,
    },
}
request = urllib.request.Request(
    base + "/api/field-solve",
    data=json.dumps(payload).encode("utf-8"),
    headers={"Content-Type": "application/json"},
)
with urllib.request.urlopen(request, timeout=30) as response:
    result = json.load(response)

job_id = result.get("job_id")
if not job_id:
    raise RuntimeError(f"Field solve did not return a job ID: {result}")

for _ in range(120):
    with urllib.request.urlopen(base + "/api/field-solve/" + job_id, timeout=30) as response:
        result = json.load(response)
    if result.get("status") == "complete":
        print("Finite-difference smoke test passed:", job_id)
        break
    if result.get("status") == "failed":
        raise RuntimeError(result)
    time.sleep(1)
else:
    raise TimeoutError(f"Field solve did not finish: {job_id}")
PY
```

FEniCSx readiness:

```bash
cd "$PROJECT_DIR"
python3 software/bias_filter/fenicsx_solver.py --json
```

Run a small FEniCSx job through the web API as well. Submit it as the agent, capture the returned `job_id`, and poll `/api/field-solve/{job_id}` until it reports `complete` or `failed`. Use this request body:

```bash
curl -fsS -X POST http://127.0.0.1/api/field-solve \
  -H 'Content-Type: application/json' \
  -d '{"client_id":"fenicsx-smoke","solver":"fenicsx","parameters":{"plate_pairs":1,"grid_r_count":24,"grid_z_count":36,"mesh_edge_radius_ratio":0.35,"load_current_na":1.0}}'
```

SPICE endpoint:

```bash
curl -fsS -X POST http://127.0.0.1/api/spice-ladder \
  -H 'Content-Type: application/json' \
  -d '{"parameters":{"frequency_start_hz":1,"frequency_stop_hz":100000000,"frequency_point_count":24}}'
```

Confirm that the SPICE response has `status: ok`. Record whether its `source` reports `ngspice-ac` or the internal modified-nodal fallback.

Run backend tests if time allows:

```bash
cd "$PROJECT_DIR"
python3 -B -m unittest software.bias_filter.test_field_backend
```

## 6. Optional Sudo Tightening For Non-Dedicated Hosts

Keep broad sudo on a Pi designated as an expendable AI development device. For a shared or longer-lived host that does not use that trust model, agree on and install a narrow sudoers file:

```bash
sudo visudo -f /etc/sudoers.d/discoidal-capacitor-bias-filter-agent
```

Suggested contents:

```text
AGENT_USER ALL=(root) NOPASSWD: /usr/bin/systemctl restart SERVICE_NAME, /usr/bin/systemctl status SERVICE_NAME, /usr/bin/systemctl is-active SERVICE_NAME
```

Replace `AGENT_USER` and `SERVICE_NAME` with the actual values before saving the sudoers file.

Only remove broad sudo after verifying the user still has an admin account.

## 7. Troubleshooting

Service logs:

```bash
journalctl -u "$SERVICE_NAME" -n 120 --no-pager
```

Service status:

```bash
systemctl status "$SERVICE_NAME" --no-pager -l
```

Common fixes:

- If port 80 fails with permission errors, confirm the service file includes `AmbientCapabilities=CAP_NET_BIND_SERVICE`.
- If FEniCSx imports fail, rerun the package install step and confirm the OS is 64-bit.
- If the page loads but solves fail, check `/api/health` and then `journalctl`.
- If static files are stale, rerun the `rsync` command from the static install step and refresh the browser.

## Final Response Requirement

End your setup response by telling the user exactly how to access the hosted page. Use the actual hostname or IP address discovered during setup:

```markdown
Hosted page: [http://PI_ADDRESS/actual-app-path/](http://PI_ADDRESS/actual-app-path/)
Backend health: [http://PI_ADDRESS/api/health](http://PI_ADDRESS/api/health)
```

Replace `PI_ADDRESS` and `actual-app-path` with the verified host and `APP_PATH` used during setup.

Also summarize which paths passed smoke tests: static page, `/api/health`, finite-difference solve, FEniCSx readiness and job, backend unit tests, and the SPICE endpoint. State whether SPICE used `ngspice` or the internal fallback.

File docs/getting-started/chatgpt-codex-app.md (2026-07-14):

# Getting Started With The Codex Desktop App

This is the recommended human workflow for the project. The Codex desktop app can open a local folder, inspect files, run commands, and keep the Raspberry Pi setup in one task.

## 1. Install The App

Install the Codex desktop app and sign in with your ChatGPT account. Start with OpenAI's current [Codex setup page](https://openai.com/codex/get-started/).

## 2. Download The Project

Return to the top of the DiscoidalCapacitorBiasFilter GitHub repository page, above the README, and select **Code**.

If Git is installed, copy the HTTPS address shown there and clone it. For this repository, the command is:

```text
git clone https://github.com/EricLarueMartin/DiscoidalCapacitorBiasFilter.git
```

If you do not use Git, choose **Download ZIP** from the same **Code** menu and extract the downloaded file. Put the project in a normal folder outside OneDrive, iCloud Drive, or another live-sync service when practical because those services can interfere with Git's internal files.

## 3. Open It In Codex

In the desktop app, open the `DiscoidalCapacitorBiasFilter` folder as the working folder and start a Codex task. Send this prompt:

```text
Read README.md, AGENT.md, and deploy/pi/agent-setup.md. Walk me through setting up a Raspberry Pi for this project. Ask only for information you cannot discover yourself. Generate the SSH key yourself, and when I need to run a command manually, give me a complete command with the actual public key and values already inserted. Continue through deployment and testing, then give me a clickable link to the working site.
```

The agent should guide Raspberry Pi Imager and physical steps conversationally, then automate everything it can from your computer. Tell it when you need more or less detail.

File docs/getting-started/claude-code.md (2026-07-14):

# Getting Started With Claude Code

Claude Code can perform the same local-repository and SSH deployment workflow from a terminal.

## 1. Install Claude Code

Follow Anthropic's current [Claude Code setup guide](https://docs.anthropic.com/en/docs/claude-code/getting-started). It covers the currently supported installation paths for macOS, Linux, WSL, and Windows. Start `claude` once and complete authentication.

## 2. Download The Project

Return to the top of the DiscoidalCapacitorBiasFilter GitHub repository page, select **Code**, and copy the HTTPS address. In a terminal, clone the repository and enter it:

```text
git clone https://github.com/EricLarueMartin/DiscoidalCapacitorBiasFilter.git
cd DiscoidalCapacitorBiasFilter
```

If you do not want to use Git, choose **Download ZIP** from the same **Code** menu, extract it, and open a terminal in the extracted `DiscoidalCapacitorBiasFilter` folder. A project folder outside OneDrive, iCloud Drive, or another live-sync service is preferable.

## 3. Start The Setup Task

Run `claude` in the repository directory and send:

```text
Read README.md, AGENT.md, and deploy/pi/agent-setup.md. Walk me through setting up a Raspberry Pi for this project. Ask only for information you cannot discover yourself. Generate the SSH key yourself, and give me complete commands with all real values inserted whenever a manual step is required. Continue through deployment and testing, then give me a clickable link to the working site.
```

Approve only the file, terminal, network, and SSH access you are comfortable granting. Full unattended deployment requires the agent to run local SSH commands and administer the dedicated Pi account.

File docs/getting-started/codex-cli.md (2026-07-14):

# Getting Started With Codex CLI

This route keeps the setup in a terminal while giving Codex direct access to the local repository.

## 1. Install Codex

Follow OpenAI's current [Codex CLI guide](https://developers.openai.com/codex/cli), then run `codex` once and sign in with ChatGPT.

## 2. Download The Project

Return to the top of the DiscoidalCapacitorBiasFilter GitHub repository page, select **Code**, and copy the HTTPS address. In a terminal, clone the repository and enter it:

```text
git clone https://github.com/EricLarueMartin/DiscoidalCapacitorBiasFilter.git
cd DiscoidalCapacitorBiasFilter
```

If you do not want to use Git, choose **Download ZIP** from the same **Code** menu, extract it, and open a terminal in the extracted `DiscoidalCapacitorBiasFilter` folder. A project folder outside OneDrive, iCloud Drive, or another live-sync service is preferable.

## 3. Start The Setup Task

Run `codex` from the repository directory and send:

```text
Read README.md, AGENT.md, and deploy/pi/agent-setup.md. Walk me through setting up a Raspberry Pi for this project. Ask only for information you cannot discover yourself. Generate the SSH key yourself, and give me complete commands with all real values inserted whenever a manual step is required. Continue through deployment and testing, then give me a clickable link to the working site.
```

The agent should pause only for physical actions, account sign-in, network details, or commands that require your approval.

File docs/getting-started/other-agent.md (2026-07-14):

# Getting Started With Another Coding Agent

Any coding agent can set up this project if it can:

- Read and edit a local repository.
- Run terminal commands on your computer.
- Create and protect an SSH key pair.
- Connect to a Raspberry Pi over SSH.
- Request approval for privileged or network operations.
- Continue through installation, service setup, and smoke testing.

Return to the top of the DiscoidalCapacitorBiasFilter GitHub repository page and select **Code**. Either choose **Download ZIP** and extract it, or copy the HTTPS address and clone the repository:

```text
git clone https://github.com/EricLarueMartin/DiscoidalCapacitorBiasFilter.git
```

Open the resulting `DiscoidalCapacitorBiasFilter` folder as the agent's project or workspace. Then send:

```text
Read README.md, AGENT.md, and deploy/pi/agent-setup.md. Walk me through setting up a Raspberry Pi for this project. Ask only for information you cannot discover yourself. Generate the SSH key yourself, and when I need to run a command manually, give me a complete command with the actual public key and values already inserted. Continue through deployment and testing, then give me a clickable link to the working site.
```

If the tool cannot run commands or connect over SSH, it can still explain the process, but it cannot provide the mostly automated workflow for which this project was designed.

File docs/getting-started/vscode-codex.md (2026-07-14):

# Getting Started With VS Code And Codex

Use this route if you want the repository visible in an editor while the agent works.

## 1. Install The Tools

Install [Visual Studio Code](https://code.visualstudio.com/) and the [official Codex extension](https://marketplace.visualstudio.com/items?itemName=openai.chatgpt). OpenAI's current guide is [Codex IDE extension](https://developers.openai.com/codex/ide).

## 2. Download And Open The Project

Return to the top of the DiscoidalCapacitorBiasFilter GitHub repository page, select **Code**, and copy the HTTPS address. Use VS Code's **Clone Git Repository** command with that address:

```text
https://github.com/EricLarueMartin/DiscoidalCapacitorBiasFilter.git
```

Choose a project folder outside a live-sync service when practical, then open the cloned `DiscoidalCapacitorBiasFilter` folder. If you do not want to use Git, choose **Download ZIP** from GitHub's **Code** menu, extract it, and open the extracted folder in VS Code.

## 3. Start The Setup Task

Open Codex in VS Code, sign in, and send:

```text
Read README.md, AGENT.md, and deploy/pi/agent-setup.md. Walk me through setting up a Raspberry Pi for this project. Ask only for information you cannot discover yourself. Generate the SSH key yourself, and give me complete commands with all real values inserted whenever a manual step is required. Continue through deployment and testing, then give me a clickable link to the working site.
```

Keep the repository folder open while the task runs so the extension has the project context.

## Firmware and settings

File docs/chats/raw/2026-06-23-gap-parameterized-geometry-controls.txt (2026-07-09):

# Raw Conversation Record: Gap-Parameterized Geometry Controls

Date: 2026-06-23

This is a reconstructed raw collaboration record from the user-visible chat context. It omits shell commands, browser automation, and routine intermediate assistant progress.

## Conversation

User: Liked that raising Ground OD also raises Tube ID to keep up, but noted the reverse behavior was poor: lowering Tube ID simply hit a limit instead of pulling Ground OD down. User said Ground OD and Tube ID should always be the same anyway. User wanted the interface to specify gaps where appropriate, such as Tube ID plus HV plate OD-to-Tube ID gap, and Core OD plus Ground ID-to-Core OD gap.

Assistant outcome: Reworked the web geometry controls so the user-facing sliders are gap-based for dependent diameters. The interface now exposes `Core OD`, `Tube ID`, `Core-ground gap`, and `HV-tube gap`. The app derives `ground_plate_od_mm = tube_id_mm`, `hv_plate_od_mm = tube_id_mm - 2 * hv_to_tube_gap_mm`, and `ground_plate_inner_diameter_mm = core_od_mm + 2 * core_to_ground_gap_mm`. The old independent HV OD, Ground ID, and Ground OD sliders were removed and replaced with derived readouts. The Python parameter loader now also derives legacy diameters from the new gap fields when present.

## Verification Note

Browser verification showed that lowering Tube ID from 36 mm to 30 mm kept the 5 mm radial HV-tube gap and changed the derived dimensions to Ground OD = 30 mm and HV OD = 20 mm. Changing the HV-tube gap and core-ground gap recalculated HV OD and Ground ID directly. The page was reset to defaults afterward, and the field solve still completed using the JavaScript fallback.

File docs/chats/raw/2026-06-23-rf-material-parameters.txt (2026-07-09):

User noted that the current frequency response is still a capacitance/RC model and asked whether FEniCS can do a full RF model for comparison. They also asked to add plate and tube material, defaulting to copper, with necessary physical parameters.

Implemented a web/model parameter pass:
- Added plate_material and tube_material controls, defaulting to copper.
- Added conductor conductivity sigma and relative permeability mu_r controls for both plates and tube.
- Added an RF comparison frequency control and skin-depth readouts for plate and tube conductors.
- Added an RF material metric strip that makes clear these are material estimates only and that the RF backend is planned.
- Added an RF Model Path slide distinguishing lumped RC, quasi-static frequency-domain admittance, and full-wave Maxwell FEM.
- Added the new conductor parameters to hardware/geometry/default-parameters.json, backend sanitization, and exported geometry summaries.
- Documented that the current FD backend remains electrostatic and treats conductors as equipotential boundaries.

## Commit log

2026-07-09 Initial sanitized SHV bias filter project snapshot
    [2026-06-23-gap-parameterized-geometry-controls.txt, 2026-06-23-rf-material-parameters.txt, latest-model.obj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]
2026-07-10 Prepare Pi onboarding and capacitance validation
2026-07-13 Document current design handoff and thermal risk
2026-07-14 Expand FEA, circuit, and material analysis
2026-07-14 Clarify Raspberry Pi memory requirements
2026-07-14 Revert "Clarify Raspberry Pi memory requirements"
    This reverts commit 40072c92e288f7d71fd6cc334972114aef52ff65.
2026-07-31 Validate thermal FEA and capacitance models
2026-08-01 Add EQS validation and thermal material studies
2026-08-06 Expand FEA, SPICE, and prototype analysis
2026-09-21 Fix mirror-asymmetric edge classification and report per-region field peaks
    Grid refinement places samples at exactly center +/- radius, landing exactly
    on the rounded plate edge arcs. The `<= radius**2` inclusion test was then an
    exact floating-point tie, and mirror-image grid points reach that comparison
    by different arithmetic paths, so they rounded opposite ways. Twelve cells at
    the bias-plate and ground-plate edges were classified as conductor at one end
    of the stack and dielectric at its mirror position, fixing spurious Dirichlet
    nodes directly on the field hot spots.
    On the default geometry this broke z-symmetry of a mirror-symmetric problem:
    mirrored points differed by up to 235 V i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
2026-09-22 Update epoxy defaults, CAEN filter model, and noise analysis
    Add DP270, EP30, and 832C material and cure data with refreshed default simulations. Model the CAEN output network, reuse FEA capacitance classes for circuit sweeps, and update the presentation including sigma-only noise comparisons.
2026-09-22 Default to seven bias plates and Designer power-line frequency
    Reuse three-plate FEA capacitances for the seven-plate SPICE result. Document the 0.094-times-Fano supply-noise allocation and make power-line comparisons follow the 50 Hz default Designer setting.
2026-09-22 Validate 28 mm default and make simulation runs explicit
2026-10-20 Separate bias and ground edge radius, with a link checkbox and mm entry
    The edge radius was a single "Edge diameter" percentage shared by both plate
    kinds, so a bias plate and a ground plate of different thickness could not be
    rounded to the same physical radius, and a radius set by a specific corner
    rounding tool could not be entered at all.
    The solver and backend already accepted bias_edge_radius_mm and
    ground_edge_radius_mm independently -- edge_radius_mm(p, kind) has honoured
    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
2026-10-27 Remove fixed 12 mm bias-plate OD floor and radial overlap rule
    Bias-plate OD is now limited only by core OD + 2 x bias edge radius, so the
    rounded outer edge fits outside the core. The fixed 12 mm minimum and the
    1 mm bias/ground radial-overlap requirement are removed from the Designer,
    field_backend and axisymmetric_model; ground-plate ID is limited to
    tube ID - 2 x ground edge radius. Non-overlapping plates are allowed.
    Verified on pi-09: FD and FEniCSx solves complete at zero overlap
    (OD = ground ID = 4.2 mm) and with no overlap (OD 5.0 mm, ground ID 8.0 mm);
    OD requests below the floor clamp to 4.2 mm. test_field_backend 67/68 (the
    pre-existing auto-mode FEniCSx 30 s timeout on this Pi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
2026-10-27 Limit tube ID, ground ID and edge radii by plate edge geometry
    Ground OD (= tube ID) must hold the ground plate's rounded inner edge:
    tube ID >= ground ID + 2 x ground edge radius. Edge radii are limited to
    min(thickness / 2, radial room): (bias OD - core OD) / 2 for the bias plate
    and (tube ID - ground ID) / 2 for the ground ring; linked edges use the
    tighter plate. The Designer's tube ID, ground ID and edge-radius sliders now
    get these bounds dynamically (static 12 mm tube floor removed), bias OD steps
    in 0.1 mm, and bounds are rounded so they land on the 0.1 mm grid. The
    epoxy breakdown standoffs are unchanged.
    Verified on pi-09: FD and FEniCSx complete with a 1 mm ground ring
    (ground ID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
2026-10-27 Give the LMFE signal-step transient time to finish on a Pi; report SPICE gaps
    On pi-09 (Raspberry Pi 4) the LMFE signal-step ngspice transient takes about
    121 s for the default design, just over its hard 120 s timeout. The AC sweeps
    still returned, so the Designer cached the payload and said "Current", but
    without lmfeSignalStep samples every SPICE-dependent slide stayed hidden.
    - spice_ladder: LMFE_SIGNAL_TIMEOUT_SECONDS default 120 -> 480 s, keeping the
    whole /api/spice-ladder request inside the browser's 600 s SPICE timeout.
    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
